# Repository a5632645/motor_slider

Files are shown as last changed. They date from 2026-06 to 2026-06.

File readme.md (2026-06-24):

# motor_slider
8个电动推子与MIDI CC的联动**原型机**测试

> [!NOTE]
> 本存储库含有大量AI生成内容，如果你不喜欢AI，请立刻返回

## 功能
8个电动推子，根据DAW MIDI CC移动位置，也能将电位器位置通过MIDI CC上传到DAW，两个操作不允许发生在同一时间，也不会进行抢占操作    
有7个推子含有原生PWM控制，另一个使用TIM+DMA写GPIO的形式模拟PWM  
电机控制器在小范围移动会产生可听的来回移动噪声  
MIDI CC目前固定为CC0~CC7  

## 额外内容
[购买电动线性电位器](https://item.taobao.com/item.htm?id=904405285742)

> 你说外壳，建议自己设计

> [!NOTE]
> 接下来的面板使用M3螺丝时选择平头的并且面板厚度不建议过厚，否则midi cc的范围会变成 2~124

立创面板源码，本人用的2.8mm(**别弄那么厚**)亚克力仍然会被压弯
```
{"type":"DOCHEAD"}||{"docType":"PANEL","client":"7755df130da93361","uuid":"ee90faf011b0bf49","updateTime":1781689268650,"version":"1781689268650"}|
{"type":"CANVAS","ticket":1,"id":"CANVAS"}||{"material":"acrylic","thickness":"2.0mm","print":"Ahead Side","craft":"Transparent","desc":"","coverColor":"white","width":"393mm","height":"579mm","originX":0,"originY":0,"orderWidth":"189.99mm","orderHeight":"151.89mm"}|
{"type":"POLY","ticket":2,"id":"e1584941ec573cd24"}||{"groupId":"0","layer":4,"rotation":0,"strokeWidth":0,"strokeStyle":"SOLID","strokeColor":"#000000","fillColor":"#000000","opacity":1,"autoClose":false,"ploys":[["ELLIPSE",0,0,1,1,0,0]],"displayFill":true,"displayStroke":true,"locked":false,"zIndex":10,"valid":true,"visible":true,"cover":1,"name":"","transScope":"PRINT&COVER","transPrint":0,"transWhite":0,"matrix":[6.889763779527534,0,380.7879488188978,0,6.889763779527534,1338.7758897637789]}|
{"type":"POLY","ticket":3,"id":"e18f4a7329a3ff436"}||{"groupId":"0","layer":4,"rotation":0,"strokeWidth":0,"strokeStyle":"SOLID","strokeColor":"#000000","fillColor":"#000000","opacity":1,"autoClose":false,"ploys":[["ELLIPSE",0,0,1,1,0,0]],"displayFill":true,"displayStroke":true,"locked":false,"zIndex":18,"valid":true,"visible":true,"cover":1,"name":"","transScope":"PRINT&COVER","transPrint":0,"transWhite":0,"matrix":[6.889763779527534,0,380.7849173228349,0,6.889763779527534,1811.2187007874004]}|
{"type":"POLY","ticket":4,"id":"ef68620ce32394071"}||{"groupId":"0","layer":4,"rotation":0,"strokeWidth":0,"strokeStyle":"SOLID","strokeColor":"#000000","fillColor":"#000000","opacity":1,"autoClose":false,"ploys":[["ELLIPSE",0,0,1,1,0,0]],"displayFill":true,"displayStroke":true,"locked":false,"zIndex":11,"valid":true,"visible":true,"cover":1,"name":"","transScope":"PRINT&COVER","transPrint":0,"transWhite":0,"matrix":[6.889763779527534,0,468.1925748031497,0,6.889763779527534,1338.779188976377]}|
{"type":"POLY","ticket":5,"id":"ee57a8df2610ad1db"}||{"groupId":"0","layer":4,"rotation":0,"strokeWidth":0,"strokeStyle":"SOLID","strokeColor":"#000000","fillColor":"#000000","opacity":1,"autoClose":false,"ploys":[["ELLIPSE",0,0,1,1,0,0]],"displayFill":true,"displayStroke":true,"locked":false,"zIndex":19,"valid":true,"visible":true,"cover":1,"name":"","transScope":"PRINT&COVER","transPrint":0,"transWhite":0,"matrix":[6.889763779527534,0,468.18954330708664,0,6.889763779527534,1811.2219999999984]}|
{"type":"POLY","ticket":6,"id":"e849a7849dee4361d"}||{"groupId":"0","layer":4,"rotation":0,"strokeWidth":0,"strokeStyle":"SOLID","strokeColor":"#000000","fillColor":"#000000","opacity":1,"autoClose":false,"ploys":[["ELLIPSE",0,0,1,1,0,0]],"displayFill":true,"displayStroke":true,"locked":false,"zIndex":12,"valid":true,"visible":true,"cover":1,"name":"","transScope":"PRINT&COVER","transPrint":0,"transWhite":0,"matrix":[6.889763779527534,0,555.5935748031496,0,6.889763779527534,1338.779188976377]}|
{"type":"POLY","ticket":7,"id":"e64859d853dfd7e9b"}||{"groupId":"0","layer":4,"rotation":0,"strokeWidth":0,"strokeStyle":"SOLID","strokeColor":"#000000","fillColor":"#000000","opacity":1,"autoClose":false,"ploys":[["ELLIPSE",0,0,1,1,0,0]],"displayFill":true,"displayStroke":true,"locked":false,"zIndex":20,"valid":true,"visible":true,"cover":1,"name":"","transScope":"PRINT&COVER","transPrint":0,"transWhite":0,"matrix":[6.889763779527534,0,555.5905433070866,0,6.889763779527534,1811.2219999999984]}|
{"type":"POLY","ticket":8,"id":"ecec94a499a380fba"}||{"groupId":"0","layer":4,"rotation":0,"strokeWidth":0,"strokeStyle":"SOLID","strokeColor":"#000000","fillColor":"#000000","opacity":1,"autoClose":false,"ploys":[["ELLIPSE",0,0,1,1,0,0]],"displayFill":true,"displayStroke":true,"locked":false,"zIndex":13,"valid":true,"visible":true,"cover":1,"name":"","transScope":"PRINT&COVER","transPrint":0,"transWhite":0,"matrix":[6.889763779527534,0,642.9955748031495,0,6.889763779527534,1338.779188976377]}|
{"type":"POLY","ticket":9,"id":"ef3ef9754e380944a"}||{"groupId":"0","layer":4,"rotation":0,"strokeWidth":0,"strokeStyle":"SOLID","strokeColor":"#000000","fillColor":"#000000","opacity":1,"autoClose":false,"ploys":[["ELLIPSE",0,0,1,1,0,0]],"displayFill":true,"displayStroke":true,"locked":false,"zIndex":21,"valid":true,"visible":true,"cover":1,"name":"","transScope":"PRINT&COVER","transPrint":0,"transWhite":0,"matrix":[6.889763779527534,0,642.9925433070866,0,6.889763779527534,1811.2219999999984]}|
{"type":"POLY","ticket":10,"id":"e9294cab0f8b4fe10"}||{"groupId":"0","layer":4,"rotation":0,"strokeWidth":0,"strokeStyle":"SOLID","strokeColor":"#000000","fillColor":"#000000","opacity":1,"autoClose":false,"ploys":[["ELLIPSE",0,0,1,1,0,0]],"displayFill":true,"displayStroke":true,"locked":false,"zIndex":14,"valid":true,"visible":true,"cover":1,"name":"","transScope":"PRINT&COVER","transPrint":0,"transWhite":0,"matrix":[6.889763779527534,0,730.3965748031495,0,6.889763779527534,1338.779188976377]}|
{"type":"POLY","ticket":11,"id":"ebccfad423ecd8b29"}||{"groupId":"0","layer":4,"rotation":0,"strokeWidth":0,"strokeStyle":"SOLID","strokeColor":"#000000","fillColor":"#000000","opacity":1,"autoClose":false,"ploys":[["ELLIPSE",0,0,1,1,0,0]],"displayFill":true,"displayStroke":true,"locked":false,"zIndex":22,"valid":true,"visible":true,"cover":1,"name":"","transScope":"PRINT&COVER","transPrint":0,"transWhite":0,"matrix":[6.889763779527534,0,730.3935433070866,0,6.889763779527534,1811.2219999999984]}|
{"type":"POLY","ticket":12,"id":"e99282393f4ec6fab"}||{"groupId":"0","layer":4,"rotation":0,"strokeWidth":0,"strokeStyle":"SOLID","strokeColor":"#000000","fillColor":"#000000","opacity":1,"autoClose":false,"ploys":[["ELLIPSE",0,0,1,1,0,0]],"displayFill":true,"displayStroke":true,"locked":false,"zIndex":15,"valid":true,"visible":true,"cover":1,"name":"","transScope":"PRINT&COVER","transPrint":0,"transWhite":0,"matrix":[6.889763779527534,0,817.7985748031496,0,6.889763779527534,1338.779188976377]}|
{"type":"POLY","ticket":13,"id":"e8b75c9436c282883"}||{"groupId":"0","layer":4,"rotation":0,"strokeWidth":0,"strokeStyle":"SOLID","strokeColor":"#000000","fillColor":"#000000","opacity":1,"autoClose":false,"ploys":[["ELLIPSE",0,0,1,1,0,0]],"displayFill":true,"displayStroke":true,"locked":false,"zIndex":23,"valid":true,"visible":true,"cover":1,"name":"","transScope":"PRINT&COVER","transPrint":0,"transWhite":0,"matrix":[6.889763779527534,0,817.7955433070866,0,6.889763779527534,1811.2219999999984]}|
{"type":"POLY","ticket":14,"id":"e2a41bdb96d65d63a"}||{"groupId":"0","layer":4,"rotation":0,"strokeWidth":0,"strokeStyle":"SOLID","strokeColor":"#000000","fillColor":"#000000","opacity":1,"autoClose":false,"ploys":[["ELLIPSE",0,0,1,1,0,0]],"displayFill":true,"displayStroke":true,"locked":false,"zIndex":16,"valid":true,"visible":true,"cover":1,"name":"","transScope":"PRINT&COVER","transPrint":0,"transWhite":0,"matrix":[6.889763779527534,0,905.2005748031496,0,6.889763779527534,1338.779188976377]}|
{"type":"POLY","ticket":15,"id":"e33940a38a94704ff"}||{"groupId":"0","layer":4,"rotation":0,"strokeWidth":0,"strokeStyle":"SOLID","strokeColor":"#000000","fillColor":"#000000","opacity":1,"autoClose":false,"ploys":[["ELLIPSE",0,0,1,1,0,0]],"displayFill":true,"displayStroke":true,"locked":false,"zIndex":24,"valid":true,"visible":true,"cover":1,"name":"","transScope":"PRINT&COVER","transPrint":0,"transWhite":0,"matrix":[6.889763779527534,0,905.1975433070867,0,6.889763779527534,1811.2219999999984]}|
{"type":"POLY","ticket":16,"id":"ee1f460c7b3ff9eb3"}||{"groupId":"0","layer":4,"rotation":0,"strokeWidth":0,"strokeStyle":"SOLID","strokeColor":"#000000","fillColor":"#000000","opacity":1,"autoClose":false,"ploys":[["ELLIPSE",0,0,1,1,0,0]],"displayFill":true,"displayStroke":true,"locked":false,"zIndex":17,"valid":true,"visible":true,"cover":1,"name":"","transScope":"PRINT&COVER","transPrint":0,"transWhite":0,"matrix":[6.889763779527534,0,992.6015748031497,0,6.889763779527534,1338.779188976377]}|
{"type":"POLY","ticket":17,"id":"e3b649b0d4ee38bb5"}||{"groupId":"0","layer":4,"rotation":0,"strokeWidth":0,"strokeStyle":"SOLID","strokeColor":"#000000","fillColor":"#000000","opacity":1,"autoClose":false,"ploys":[["ELLIPSE",0,0,1,1,0,0]],"displayFill":true,"displayStroke":true,"locked":false,"zIndex":25,"valid":true,"visible":true,"cover":1,"name":"","transScope":"PRINT&COVER","transPrint":0,"transWhite":0,"matrix":[6.889763779527534,0,992.5985433070867,0,6.889763779527534,1811.2219999999984]}|
{"type":"POLY","ticket":18,"id":"ec19dd633df9f9027"}||{"groupId":"0","layer":4,"rotation":0,"strokeWidth":0,"strokeStyle":"SOLID","strokeColor":"#000000","fillColor":"#000000","opacity":1,"autoClose":false,"ploys":[["ELLIPSE",0,0,1,1,0,0]],"displayFill":true,"displayStroke":true,"locked":false,"zIndex":26,"valid":true,"visible":true,"cover":1,"name":"","transScope":"PRINT&COVER","transPrint":0,"transWhite":0,"matrix":[6.889763779527534,0,327.16507480314976,0,6.889763779527534,1850.7869291338563]}|
{"type":"POLY","ticket":19,"id":"e5c19595f2625c8ff"}||{"groupId":"0","layer":4,"rotation":0,"strokeWidth":0,"strokeStyle":"SOLID","strokeColor":"#000000","fillColor":"#000000","opacity":1,"autoClose":false,"ploys":[["ELLIPSE",0,0,1,1,0,0]],"displayFill":true,"displayStroke":true,"locked":false,"zIndex":27,"valid":true,"visible":true,"cover":1,"name":"","transScope":"PRINT&COVER","transPrint":0,"transWhite":0,"matrix":[6.889763779527534,0,327.1644094488191,0,6.889763779527534,1306.3316220472423]}|
{"type":"POLY","ticket":20,"id":"e6e8d903b9c234424"}||{"groupId":"0","layer":4,"rotation":0,"strokeWidth":0,"strokeStyle":"SOLID","strokeColor":"#000000","fillColor":"#000000","opacity":1,"autoClose":false,"ploys":[["ELLIPSE",0,0,1,1,0,0]],"displayFill":true,"displayStroke":true,"locked":false,"zIndex":28,"valid":true,"visible":true,"cover":1,"name":"","transScope":"PRINT&COVER","transPrint":0,"transWhite":0,"matrix":[6.889763779527534,0,1040.9346889763783,0,6.889763779527534,1306.3313228346442]}|
{"type":"POLY","ticket":21,"id":"e58a1011d351861f7"}||{"groupId":"0","layer":4,"rotation":0,"strokeWidth":0,"strokeStyle":"SOLID","strokeColor":"#000000","fillColor":"#000000","opacity":1,"autoClose":false,"ploys":[["ELLIPSE",0,0,1,1,0,0]],"displayFill":true,"displayStroke":true,"locked":false,"zIndex":29,"valid":true,"visible":true,"cover":1,"name":"","transScope":"PRINT&COVER","transPrint":0,"transWhite":0,"matrix":[6.889763779527534,0,1040.9354921259842,0,6.889763779527534,1850.7872834645655]}|
{"type":"POLY","ticket":22,"id":"e03eb1e0feb6fb015"}||{"groupId":"0","layer":3,"rotation":0,"strokeWidth":0,"strokeStyle":"SOLID","strokeColor":"#000000","fillColor":"#000000","opacity":1,"autoClose":false,"ploys":[["R",0,0,1,1,0,0,0,0]],"displayFill":true,"displayStroke":true,"locked":false,"zIndex":9,"valid":true,"visible":true,"cover":1,"name":"","transScope":"PRINT&COVER","transPrint":0,"transWhite":0,"matrix":[748,-2.343515398637612e-15,311.00000000000006,-3.210431588880691e-15,597.9999999999999,1874]}|
{"type":"POLY","ticket":23,"id":"e8425d0d29416879a"}||{"groupId":"0","layer":1,"rotation":0,"strokeWidth":3.937007874015748,"strokeStyle":"SOLID","strokeColor":"#000000","fillColor":"#000000","opacity":1,"autoClose":false,"ploys":[["R",0,0,1,1,0,0,0,0]],"displayFill":false,"displayStroke":true,"locked":false,"zIndex":1,"valid":true,"visible":true,"cover":1,"name":"","transScope":"PRINT&COVER","transPrint":0,"transWhite":0,"matrix":[67.71653543307086,0,346.92671259842524,0,576.771653543307,1863.3824173228334]}|
{"type":"POLY","ticket":24,"id":"ed294a9686753e663"}||{"groupId":"0","layer":4,"rotation":0,"strokeWidth":0,"strokeStyle":"SOLID","strokeColor":"#000000","fillColor":"#000000","opacity":1,"autoClose":false,"ploys":[["R",0,0,1,1,0,0,0,0]],"displayFill":true,"displayStroke":true,"locked":false,"zIndex":30,"valid":true,"visible":true,"cover":1,"name":"","transScope":"PRINT&COVER","transPrint":0,"transWhite":0,"matrix":[9.842519685039406,0,375.8628543307085,0,433.07086614173227,1791.5328503936992]}|
{"type":"POLY","ticket":25,"id":"ef3a6cacf585e59a6"}||{"groupId":"0","layer":1,"rotation":0,"strokeWidth":3.937007874015748,"strokeStyle":"SOLID","strokeColor":"#000000","fillColor":"#000000","opacity":1,"autoClose":false,"ploys":[["R",0,0,1,1,0,0,0,0]],"displayFill":false,"displayStroke":true,"locked":false,"zIndex":2,"valid":true,"visible":true,"cover":1,"name":"","transScope":"PRINT&COVER","transPrint":0,"transWhite":0,"matrix":[67.71653543307086,0,434.3313385826771,0,576.771653543307,1863.3857165354316]}|
{"type":"POLY","ticket":26,"id":"e583333e3c7230aa1"}||{"groupId":"0","layer":4,"rotation":0,"strokeWidth":0,"strokeStyle":"SOLID","strokeColor":"#000000","fillColor":"#000000","opacity":1,"autoClose":false,"ploys":[["R",0,0,1,1,0,0,0,0]],"displayFill":true,"displayStroke":true,"locked":false,"zIndex":31,"valid":true,"visible":true,"cover":1,"name":"","transScope":"PRINT&COVER","transPrint":0,"transWhite":0,"matrix":[9.842519685039406,0,463.2674803149603,0,433.07086614173227,1791.5361496062974]}|
{"type":"POLY","ticket":27,"id":"eaf03c847e17b207d"}||{"groupId":"0","layer":1,"rotation":0,"strokeWidth":3.937007874015748,"strokeStyle":"SOLID","strokeColor":"#000000","fillColor":"#000000","opacity":1,"autoClose":false,"ploys":[["R",0,0,1,1,0,0,0,0]],"displayFill":false,"displayStroke":true,"locked":false,"zIndex":3,"valid":true,"visible":true,"cover":1,"name":"","transScope":"PRINT&COVER","transPrint":0,"transWhite":0,"matrix":[67.71653543307086,0,521.7323385826771,0,576.771653543307,1863.3857165354316]}|
{"type":"POLY","ticket":28,"id":"e2db45f8716f7ab01"}||{"groupId":"0","layer":4,"rotation":0,"strokeWidth":0,"strokeStyle":"SOLID","strokeColor":"#000000","fillColor":"#000000","opacity":1,"autoClose":false,"ploys":[["R",0,0,1,1,0,0,0,0]],"displayFill":true,"displayStroke":true,"locked":false,"zIndex":32,"valid":true,"visible":true,"cover":1,"name":"","transScope":"PRINT&COVER","transPrint":0,"transWhite":0,"matrix":[9.842519685039406,0,550.6684803149603,0,433.07086614173227,1791.5361496062974]}|
{"type":"POLY","ticket":29,"id":"eb4fa830be97bb013"}||{"groupId":"0","layer":1,"rotation":0,"strokeWidth":3.937007874015748,"strokeStyle":"SOLID","strokeColor":"#000000","fillColor":"#000000","opacity":1,"autoClose":false,"ploys":[["R",0,0,1,1,0,0,0,0]],"displayFill":false,"displayStroke":true,"locked":false,"zIndex":4,"valid":true,"visible":true,"cover":1,"name":"","transScope":"PRINT&COVER","transPrint":0,"transWhite":0,"matrix":[67.71653543307086,0,609.1343385826772,0,576.771653543307,1863.3857165354316]}|
{"type":"POLY","ticket":30,"id":"e0a4fecc1b48feb2d"}||{"groupId":"0","layer":4,"rotation":0,"strokeWidth":0,"strokeStyle":"SOLID","strokeColor":"#000000","fillColor":"#000000","opacity":1,"autoClose":false,"ploys":[["R",0,0,1,1,0,0,0,0]],"displayFill":true,"displayStroke":true,"locked":false,"zIndex":33,"valid":true,"visible":true,"cover":1,"name":"","transScope":"PRINT&COVER","transPrint":0,"transWhite":0,"matrix":[9.842519685039406,0,638.0704803149604,0,433.07086614173227,1791.5361496062974]}|
{"type":"POLY","ticket":31,"id":"ea5e9c516e7580935"}||{"groupId":"0","layer":1,"rotation":0,"strokeWidth":3.937007874015748,"strokeStyle":"SOLID","strokeColor":"#000000","fillColor":"#000000","opacity":1,"autoClose":false,"ploys":[["R",0,0,1,1,0,0,0,0]],"displayFill":false,"displayStroke":true,"locked":false,"zIndex":5,"valid":true,"visible":true,"cover":1,"name":"","transScope":"PRINT&COVER","transPrint":0,"transWhite":0,"matrix":[67.71653543307086,0,696.5353385826771,0,576.771653543307,1863.3857165354316]}|
{"type":"POLY","ticket":32,"id":"ed69e7dfbb81d9574"}||{"groupId":"0","layer":4,"rotation":0,"strokeWidth":0,"strokeStyle":"SOLID","strokeColor":"#000000","fillColor":"#000000","opacity":1,"autoClose":false,"ploys":[["R",0,0,1,1,0,0,0,0]],"displayFill":true,"displayStroke":true,"locked":false,"zIndex":34,"valid":true,"visible":true,"cover":1,"name":"","transScope":"PRINT&COVER","transPrint":0,"transWhite":0,"matrix":[9.842519685039406,0,725.4714803149603,0,433.07086614173227,1791.5361496062974]}|
{"type":"POLY","ticket":33,"id":"ee4c32a7e6f3f4fc2"}||{"groupId":"0","layer":1,"rotation":0,"strokeWidth":3.937007874015748,"strokeStyle":"SOLID","strokeColor":"#000000","fillColor":"#000000","opacity":1,"autoClose":false,"ploys":[["R",0,0,1,1,0,0,0,0]],"displayFill":false,"displayStroke":true,"locked":false,"zIndex":6,"valid":true,"visible":true,"cover":1,"name":"","transScope":"PRINT&COVER","transPrint":0,"transWhite":0,"matrix":[67.71653543307086,0,783.9373385826772,0,576.771653543307,1863.3857165354316]}|
{"type":"POLY","ticket":34,"id":"e7ed778951e0f1ca9"}||{"groupId":"0","layer":4,"rotation":0,"strokeWidth":0,"strokeStyle":"SOLID","strokeColor":"#000000","fillColor":"#000000","opacity":1,"autoClose":false,"ploys":[["R",0,0,1,1,0,0,0,0]],"displayFill":true,"displayStroke":true,"locked":false,"zIndex":35,"valid":true,"visible":true,"cover":1,"name":"","transScope":"PRINT&COVER","transPrint":0,"transWhite":0,"matrix":[9.842519685039406,0,812.8734803149604,0,433.07086614173227,1791.5361496062974]}|
{"type":"POLY","ticket":35,"id":"efc2624c844171aa8"}||{"groupId":"0","layer":1,"rotation":0,"strokeWidth":3.937007874015748,"strokeStyle":"SOLID","strokeColor":"#000000","fillColor":"#000000","opacity":1,"autoClose":false,"ploys":[["R",0,0,1,1,0,0,0,0]],"displayFill":false,"displayStroke":true,"locked":false,"zIndex":7,"valid":true,"visible":true,"cover":1,"name":"","transScope":"PRINT&COVER","transPrint":0,"transWhite":0,"matrix":[67.71653543307086,0,871.3393385826772,0,576.771653543307,1863.3857165354316]}|
{"type":"POLY","ticket":36,"id":"e7c086de920a9acdd"}||{"groupId":"0","layer":4,"rotation":0,"strokeWidth":0,"strokeStyle":"SOLID","strokeColor":"#000000","fillColor":"#000000","opacity":1,"autoClose":false,"ploys":[["R",0,0,1,1,0,0,0,0]],"displayFill":true,"displayStroke":true,"locked":false,"zIndex":36,"valid":true,"visible":true,"cover":1,"name":"","transScope":"PRINT&COVER","transPrint":0,"transWhite":0,"matrix":[9.842519685039406,0,900.2754803149604,0,433.07086614173227,1791.5361496062974]}|
{"type":"POLY","ticket":37,"id":"e8287a6ea15dcac1f"}||{"groupId":"0","layer":1,"rotation":0,"strokeWidth":3.937007874015748,"strokeStyle":"SOLID","strokeColor":"#000000","fillColor":"#000000","opacity":1,"autoClose":false,"ploys":[["R",0,0,1,1,0,0,0,0]],"displayFill":false,"displayStroke":true,"locked":false,"zIndex":8,"valid":true,"visible":true,"cover":1,"name":"","transScope":"PRINT&COVER","transPrint":0,"transWhite":0,"matrix":[67.71653543307086,0,958.7403385826772,0,576.771653543307,1863.3857165354316]}|
{"type":"POLY","ticket":38,"id":"e680f056dc145cdaa"}||{"groupId":"0","layer":4,"rotation":0,"strokeWidth":0,"strokeStyle":"SOLID","strokeColor":"#000000","fillColor":"#000000","opacity":1,"autoClose":false,"ploys":[["R",0,0,1,1,0,0,0,0]],"displayFill":true,"displayStroke":true,"locked":false,"zIndex":37,"valid":true,"visible":true,"cover":1,"name":"","transScope":"PRINT&COVER","transPrint":0,"transWhite":0,"matrix":[9.842519685039406,0,987.6764803149604,0,433.07086614173227,1791.5361496062974]}|
{"type":"AUXLINE","ticket":39,"id":"e78fae264d32af79d"}||{"groupId":"0","layer":8,"x":327.55781496063,"y":1850.786787401573,"rotation":0,"strokeWidth":0,"length":100,"locked":false,"visible":true,"cover":0,"name":"","zIndex":54}|
{"type":"AUXLINE","ticket":40,"id":"ee2bd2ee56e85e5eb"}||{"groupId":"0","layer":8,"x":327.1645944881891,"y":1883.0706535433055,"rotation":90,"strokeWidth":0,"length":100,"locked":false,"visible":true,"cover":0,"name":"","zIndex":55}|
{"type":"AUXLINE","ticket":41,"id":"e86db9603efb5b519"}||{"groupId":"0","layer":8,"x":1040.9349803149605,"y":1883.0705511811009,"rotation":90,"strokeWidth":0,"length":100,"locked":false,"visible":true,"cover":0,"name":"","zIndex":56}|
{"type":"AUXLINE","ticket":42,"id":"ebabefe86aa5f8d13"}||{"groupId":"0","layer":8,"x":326.77086614173254,"y":1306.3321181102347,"rotation":0,"strokeWidth":0,"length":100,"locked":false,"visible":true,"cover":0,"name":"","zIndex":57}|
{"type":"AUXLINE","ticket":43,"id":"ebd909c018683e468"}||{"groupId":"0","layer":8,"x":468.1895433070866,"y":1575.0000512529068,"rotation":0,"strokeWidth":0,"length":0,"locked":false,"visible":true,"cover":0,"name":"","zIndex":40}|
{"type":"AUXLINE","ticket":44,"id":"efa1f53fa5ae68d26"}||{"groupId":"0","layer":8,"x":555.5905433070866,"y":1575.0000512529068,"rotation":0,"strokeWidth":0,"length":0,"locked":false,"visible":true,"cover":0,"name":"","zIndex":41}|
{"type":"AUXLINE","ticket":45,"id":"ebb5dc5efb9204c62"}||{"groupId":"0","layer":8,"x":642.9925433070866,"y":1575.0000512529068,"rotation":0,"strokeWidth":0,"length":0,"locked":false,"visible":true,"cover":0,"name":"","zIndex":42}|
{"type":"AUXLINE","ticket":46,"id":"e73e467c0f45ccb31"}||{"groupId":"0","layer":8,"x":730.3935433070866,"y":1575.0000512529068,"rotation":0,"strokeWidth":0,"length":0,"locked":false,"visible":true,"cover":0,"name":"","zIndex":43}|
{"type":"AUXLINE","ticket":47,"id":"eac48020f18635c06"}||{"groupId":"0","layer":8,"x":817.7955433070866,"y":1575.0000512529068,"rotation":0,"strokeWidth":0,"length":0,"locked":false,"visible":true,"cover":0,"name":"","zIndex":44}|
{"type":"AUXLINE","ticket":48,"id":"eb4071d14bd4ca49d"}||{"groupId":"0","layer":8,"x":905.1975433070867,"y":1575.0000512529068,"rotation":0,"strokeWidth":0,"length":0,"locked":false,"visible":true,"cover":0,"name":"","zIndex":45}|
{"type":"AUXLINE","ticket":49,"id":"ed3d01fe15ed1ee86"}||{"groupId":"0","layer":8,"x":992.5985433070866,"y":1575.0000512529068,"rotation":0,"strokeWidth":0,"length":0,"locked":false,"visible":true,"cover":0,"name":"","zIndex":46}|
{"type":"DIMENSION","ticket":50,"id":"e41ac982d3f6c6d03"}||{"layer":8,"dimensionType":"LENGTH","unit":"","strokeWidth":0,"accuracy":0,"controlDot":[380.78491732283476,1811.2187007874004,429.5277283464569,1811.2187007874004,429.5277283464569,1338.775889763779,380.7879488188978,1338.775889763779],"relationIds":[],"locked":false,"zIndex":38,"visible":true,"cover":0,"name":"","valid":true,"rotation":0}|
{"type":"DIMENSION","ticket":51,"id":"e5a79f0815a55690b"}||{"layer":8,"dimensionType":"LENGTH","unit":"","strokeWidth":0,"accuracy":0,"controlDot":[380.7879488188978,1338.775889763779,357.92470540636003,1338.7757430585466,357.92318966431577,1574.9962154946286,380.78643307685354,1574.996362199861],"relationIds":[],"locked":false,"zIndex":39,"visible":true,"cover":0,"name":"","valid":true,"rotation":0}|
{"type":"DIMENSION","ticket":52,"id":"e1cdcaf0fb6a92284"}||{"layer":8,"dimensionType":"LENGTH","unit":"","strokeWidth":0,"accuracy":0,"controlDot":[414.64279921259845,1286.611188976375,414.64279921259845,1286.6104803149585,434.3277204724409,1286.6104803149585,434.3277204724409,1286.611787401572],"relationIds":[],"locked":false,"zIndex":47,"visible":true,"cover":0,"name":"","valid":true,"rotation":0}|
{"type":"DIMENSION","ticket":53,"id":"edc10f024f0ffa6eb"}||{"layer":8,"dimensionType":"LENGTH","unit":"","strokeWidth":0,"accuracy":0,"controlDot":[502.04742519685027,1286.6144881889732,502.04742519685027,1286.6137795275567,521.7323464566925,1286.6137795275567,521.7323464566925,1286.6150866141702],"relationIds":[],"locked":false,"zIndex":48,"visible":true,"cover":0,"name":"","valid":true,"rotation":0}|
{"type":"DIMENSION","ticket":54,"id":"eee07e3357b190a82"}||{"layer":8,"dimensionType":"LENGTH","unit":"","strokeWidth":0,"accuracy":0,"controlDot":[589.4484251968502,1286.6144881889732,589.4484251968502,1286.6137795275567,609.1333464566927,1286.6137795275567,609.1333464566927,1286.6150866141702],"relationIds":[],"locked":false,"zIndex":49,"visible":true,"cover":0,"name":"","valid":true,"rotation":0}|
{"type":"DIMENSION","ticket":55,"id":"e27bef0ec3e5497e1"}||{"layer":8,"dimensionType":"LENGTH","unit":"","strokeWidth":0,"accuracy":0,"controlDot":[676.8504251968502,1286.6144881889732,676.8504251968502,1286.6137795275567,696.5353464566928,1286.6137795275567,696.5353464566928,1286.6150866141702],"relationIds":[],"locked":false,"zIndex":50,"visible":true,"cover":0,"name":"","valid":true,"rotation":0}|
{"type":"DIMENSION","ticket":56,"id":"e288bcc642b5978d1"}||{"layer":8,"dimensionType":"LENGTH","unit":"","strokeWidth":0,"accuracy":0,"controlDot":[764.2514251968502,1286.6144881889732,764.2514251968502,1286.6137795275567,783.9363464566927,1286.6137795275567,783.9363464566927,1286.6150866141702],"relationIds":[],"locked":false,"zIndex":51,"visible":true,"cover":0,"name":"","valid":true,"rotation":0}|
{"type":"DIMENSION","ticket":57,"id":"ea360c81e44c1357d"}||{"layer":8,"dimensionType":"LENGTH","unit":"","strokeWidth":0,"accuracy":0,"controlDot":[851.6534251968502,1286.6144881889732,851.6534251968502,1286.6137795275567,871.3383464566928,1286.6137795275567,871.3383464566928,1286.6150866141702],"relationIds":[],"locked":false,"zIndex":52,"visible":true,"cover":0,"name":"","valid":true,"rotation":0}|
{"type":"DIMENSION","ticket":58,"id":"eaa61114e2d80f349"}||{"layer":8,"dimensionType":"LENGTH","unit":"","strokeWidth":0,"accuracy":0,"controlDot":[939.0554251968503,1286.6144881889732,939.0554251968503,1286.6137795275567,958.7403464566928,1286.6137795275567,958.7403464566928,1286.6150866141702],"relationIds":[],"locked":false,"zIndex":53,"visible":true,"cover":0,"name":"","valid":true,"rotation":0}
```

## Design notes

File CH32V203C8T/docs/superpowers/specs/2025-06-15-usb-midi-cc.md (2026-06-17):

# USB MIDI CC 双向联动 设计

> **日期:** 2025-06-15
> **关联:** `midi_cc.md`, `2025-06-12-closed-loop-control.md`, `2025-06-12-motor-control.md`

## 1. 概述

在现有 USB HID 功能不变的前提下，扩展为 USB 复合设备，新增 USB MIDI 1.0 类接口，实现八路马达线性电位器位置与 MIDI CC 消息的双向联动。

### 约束

- 不修改现有 HID 描述符、端点配置、轮询行为
- 不引入动态内存分配，所有缓冲区静态分配

---

## 2. USB 设备结构

### 2.1 复合设备拓扑

```
USB Device (bcdUSB=0x0200, Class=0xEF/0x02/0x01 Composite)
└── Configuration Descriptor (1 config)
    ├── Interface 0: HID0 (printf 调试输出, IN only) — 不变
    ├── Interface 1: HID1 (电机控制, IN + OUT) — 不变
    ├── Interface Association Descriptor (IAD)
    │   ├── bFunctionClass=1 (Audio)
    │   ├── bFunctionSubClass=3 (MIDIStreaming)
    │   └── bFunctionProtocol=0
    │   │
    │   ├── Interface 2: Audio Control (bClass=1, bSubClass=1)
    │   │   └── 无端点
    │   │
    │   └── Interface 3: MIDI Streaming (bClass=1, bSubClass=3)
    │       ├── Bulk IN  EP (0x84, 64 bytes) — MCU → Host
    │       └── Bulk OUT EP (0x05, 64 bytes) — Host → MCU
```

### 2.2 端点分配

| 端点 | 方向 | 用途 | 类型 | 包大小 |
|---|---|---|---|---|
| EP0 | 双向 | 控制传输 | Control | 64 |
| EP1 | IN (0x81) | HID0 printf | Interrupt | 64 |
| EP2 | IN (0x82) | HID1 状态上报 | Interrupt | 64 |
| EP3 | OUT (0x03) | HID1 命令接收 | Interrupt | 64 |
| **EP4** | **IN (0x84)** | **MIDI Bulk TX** | **Bulk** | **64** |
| **EP5** | **OUT (0x05)** | **MIDI Bulk RX** | **Bulk** | **64** |

### 2.3 描述符变更

**Device Descriptor (`usb_desc.cpp`)**
- `bcdUSB`: `0x0110` → `0x0200`
- `bDeviceClass`/`bDeviceSubClass`/`bDeviceProtocol`: 保持 `0xEF`/`0x02`/`0x01`（`.Composite()` 调用）

**Configuration Descriptor (`usb_desc.cpp`)**
- 在现有两个 HID Interface 之后追加 IAD + AC Interface + MIDI Streaming Interface
- 使用 tpusb 基础设施：`InterfaceAssociation`, `uac2::AudioFunction`, `midiv1::MIDIStreamInterface`, `midiv1::MidiEndpoint`

**字符串描述符**
- 保持不变

---

## 3. MIDI 数据格式

### 3.1 USB MIDI Event Packet (4 字节)

```
Byte 0: Cable Number (高4位) | Code Index Number (低4位)
Byte 1: MIDI Status Byte  (e.g. 0xB0 | channel)
Byte 2: MIDI Data Byte 1  (CC 编号)
Byte 3: MIDI Data Byte 2  (CC 值)
```

本设计仅处理 **Control Change (CC)** 消息，CIN = `0x0B`，Cable Number = `0x00`。

### 3.2 数值映射

```
电位器原始值 (0~4095) → MIDI CC (0~127)
  cc_value = raw_adc * 127 / 4095

MIDI CC (0~127) → 目标位置 (0~4095)
  target_pos = cc_value * 4095 / 127
```

---

## 4. TX 方向：电位器 → MIDI CC 发送

### 4.1 触发条件

- 在 1kHz 控制循环中，每路 ADC 更新后检查位置变化
- 仅当映射后的 CC 值与 `last_sent_cc[i]` **不同**时，才发送

### 4.2 阻塞接口模式

FIFO 满时**循环等待**而非丢弃（MIDI CC 消息不允许丢包），Flush 全部由 SysTick 驱动：

```c
// 检查连接 → 等待空间 → 入队（不触发 Flush）
void MidiCC_Send(uint8_t idx, uint8_t cc_value) {
    if (!HID_IsConnected())       // USB 未连接时跳过
        return;
    // 构造 4 字节 Event Packet
    uint8_t packet[4] = {
        0x0B,                     // CIN=0x0B (CC), Cable=0
        (uint8_t)(0xB0 | kMidiCcMap[idx].channel),
        kMidiCcMap[idx].cc_num,
        cc_value
    };
    // 等待 FIFO 有足够空间（循环等待，由 SysTick 消费腾空）
    while (Kfifo_FreeSpace(&midi_tx_fifo_.fifo) < 4) {
        // SysTick_Handler 中的 MidiCC_Flush() 会在此循环期间被响应
    }
    Kfifo_TryPush(&midi_tx_fifo_.fifo, packet, 4);
}
```

- `MidiCC_Send()` 为**阻塞式**：入队前循环等待 FIFO 空间，入队后立即返回
- **不调用** `MidiCC_Flush()` — 全部由 `SysTick_Handler` 周期性发送
- USB 未连接时 (`using_configuration == 0`)，静默丢弃，不浪费 CPU
- 等待发生在 **主循环上下文**（`Motor_RunControlLoop` 内），SysTick 中断仍正常响应并消费 FIFO

### 4.3 TX 数据流

```
Motor_RunControlLoop()  — 1kHz 控制上下文
  → 读取 ADC, 计算映射 cc_value
  → if !fader_rx_active[i] && cc_value != last_sent_cc[i]:
      → MidiCC_Send(i, cc_value)          // 仅入队，不 Flush
      → last_sent_cc[i] = cc_value

SysTick_Handler (1ms)    — 周期性发送
  → MidiCC_Flush()
    → if midi_tx_busy: return
    → 从 midi_tx_fifo_ 读取最多 64 字节 (16 packets)
    → 填充 midi_ep4_tx_buf_
    → midi_tx_busy = true
    → USBFSD->UEP4_TX_LEN = to_read
    → 触发 Bulk IN 传输

EP4 IN Complete 中断      — 流水线递送
  → midi_tx_busy = false
  → 递归 MidiCC_Flush() 直到 FIFO 空
```

### 4.4 Bulk 零包 (ZLP) 处理

Bulk 传输要求任何 **恰好 64 字节**（wMaxPacketSize 整数倍）的数据包后，需发送零长度包 (ZLP) 以标记传输结束，否则主机会等待更多数据。

```c
// Flush 内部逻辑：
uint32_t to_read = Kfifo_Size(&midi_tx_fifo_);
if (to_read == 0) {
    if (midi_zlp_needed_) {
        midi_zlp_needed_ = false;
        USBFSD->UEP4_TX_LEN = 0;          // 发送 ZLP
        midi_tx_busy = true;
    }
    return;
}
if (to_read > 64)
    to_read = 64;
// 从 FIFO 读取到 midi_ep4_tx_buf_
midi_zlp_needed_ = (to_read == 64);       // 若恰好 64 字节，标记需要 ZLP
USBFSD->UEP4_TX_LEN = to_read;
midi_tx_busy = true;
```

- `midi_zlp_needed_` 在发送 64 字节时置位
- 下次 `MidiCC_Flush()` 在 FIFO 空时检测到此标志，发送 ZLP
- ZLP 发送后清除标志，恢复正常 NAK 状态

### 4.5 Flush 调用链

```
SysTick_Handler (1ms)
  → Tick_Increment()
  → HID_Flush()              // HID0 printf 原样保留
  → MidiCC_Flush()           // MIDI TX flush（新增）

EP4 IN Complete 中断
  → midi_tx_busy = false
  → MidiCC_Flush()           // 递归发送下一批
```

- **SysTick** 提供周期性发送机会，确保 FIFO 中的数据不会长期滞留
- **EP4 IN Complete** 实现流水线：一批发送完成后立即发送下一批，最大化吞吐

### 4.6 缓冲区

```c
#define MIDI_TX_FIFO_SIZE 128   // 32 个 MIDI Event Packet
static struct {
    struct Kfifo fifo;
    uint8_t buf[MIDI_TX_FIFO_SIZE];
} midi_tx_fifo_;

__attribute__((aligned(4))) static uint8_t midi_ep4_tx_buf_[64];

static volatile bool midi_tx_busy_;
static bool midi_zlp_needed_;   // 非 volatile，仅主循环/SysTick 访问
```

---

## 5. RX 方向：MIDI CC → 电位器驱动

### 5.1 数据流

RX 采用**中断仅记录 + NAK，主线程消费**的简单设计：

```
EP5 OUT Complete (中断)
  → if midi_rx_pending_len_ > 0:
      return                                    // 上一包尚未消费，NAK 已设置
  → len = USBFSD->RX_LEN
  → if len == 0:
      USBFSD->UEP5_RX_CTRL = ACK                // ZLP 直接 ACK，无需处理
      return
  → midi_rx_pending_len_ = len                  // 记录数据长度
  → USBFSD->UEP5_RX_CTRL = NAK                  // NAK，数据留在 DMA 缓冲区等待主线程

App_Loop() 主循环
  → MidiCC_ProcessRx()
    → if midi_rx_pending_len_ == 0:
        return
    → 从 midi_ep5_rx_buf_ 中以 4 字节为单位解析 Event Packet
    → for offset = 0; offset + 3 < midi_rx_pending_len_; offset += 4:
      → 解析 CIN/Status/Data1/Data2
      → if (status & 0xF0) == 0xB0:   // CC 消息
          → 查 CC 映射表 → 定位电位器编号
          → 反向映射: target_pos = cc_value * 4095 / 127
          → fader_rx_active[idx] = true
          → Motor_SetTarget(idx, target_pos)
      → 非 CC 消息静默丢弃
    → midi_rx_pending_len_ = 0
    → USBFSD->UEP5_RX_CTRL = ACK                // 全部消耗，重新武装 EP5
```

**原理说明：**

- 中断中**不操作 FIFO**，仅记录长度 + NAK，最小化中断耗时
- 主机收到 NAK 后自动重试同一 OUT 事务，硬件将相同数据重新写入 DMA 缓冲区，数据安全
- ZLP（零长度包）无需处理，直接 ACK
- 主循环直接解析 USB DMA 缓冲区，全部消耗完后 ACK
- NAK 期间后续 OUT 中断因 `midi_rx_pending_len_ > 0` 而直接返回

### 5.2 缓冲区

```c
__attribute__((aligned(4))) static uint8_t midi_ep5_rx_buf_[64];
static volatile uint8_t midi_rx_pending_len_;    // 0 = 无待处理数据
```

---

## 6. 防回环

### 6.1 原理

当 MCU 正在响应 RX 命令驱动某路电位器时，该路电位器的位置变化不得触发 TX 发送。

### 6.2 实现

```c
static bool fader_rx_active_[kMotorIdx_Count];

// RX 驱动时置位
void MidiCC_SetRxActive(uint8_t idx, bool active) {
    if (idx < kMotorIdx_Count)
        fader_rx_active_[idx] = active;
}

// TX 检测时跳过被标记通道
// (在 MidiCC_CheckAndSend 中实现)

// 清除时机：
// 1. Motor_RunControlLoop 中 active_ 从 true → false 时清除
// 2. 超时 1000ms (CTRL_TIMEOUT_MS) 强制清除
```

### 6.3 清除逻辑

在 `Motor_RunControlLoop()` 中，每路电机到达目标或超时停止后（`active_` 从 `true` → `false`），调用 `MidiCC_SetRxActive(i, false)`。

若电机在 `CTRL_TIMEOUT_MS` (1000ms) 内未到达目标，控制超时机制会停止电机并清除 `active_`，防回环标志随之清除。

---

## 7. CC 映射配置

### 7.1 默认映射表

| 电位器编号 | MIDI 通道 (1-based) | CC 编号 |
|:---:|:---:|:---:|
| 0 | 1 | 0 |
| 1 | 1 | 1 |
| 2 | 1 | 2 |
| 3 | 1 | 3 |
| 4 | 1 | 4 |
| 5 | 1 | 5 |
| 6 | 1 | 6 |
| 7 | 1 | 7 |

### 7.2 代码定义

```c
struct MidiCcMapping {
    uint8_t channel;  // 0-based (0=Channel 1)
    uint8_t cc_num;   // CC 编号 (0~127)
};

static const struct MidiCcMapping kMidiCcMap[kMotorIdx_Count] = {
    {0, 0},   // 电位器0 → Channel 1, CC 0
    {0, 1},   // 电位器1 → Channel 1, CC 1
    {0, 2},   // 电位器2 → Channel 1, CC 2
    {0, 3},   // 电位器3 → Channel 1, CC 3
    {0, 4},   // 电位器4 → Channel 1, CC 4
    {0, 5},   // 电位器5 → Channel 1, CC 5
    {0, 6},   // 电位器6 → Channel 1, CC 6
    {0, 7},   // 电位器7 → Channel 1, CC 7
};
```

---

## 8. 文件变更清单

### 8.1 新增文件

| 文件 | 内容 |
|---|---|
| `User/usb/midi_cc.h` | MIDI CC 模块公共 API 声明 + 常量 + 映射表 |
| `User/usb/midi_cc.c` | MIDI CC 模块实现：TX/RX FIFO 管理、包解析、发送逻辑 |

### 8.2 修改文件

| 文件 | 改动 |
|---|---|
| `User/usb/usb_desc.cpp` | bcdUSB 0x0110→0x0200；追加 IAD + AC + MIDI Streaming 描述符 |
| `User/usb/usb_impl.h` | 新增 MIDI 端点地址常量 (`kMidiEpAddr_In=0x84`, `kMidiEpAddr_Out=0x05`) |
| `User/usb/usb_impl.c` | `UsbImpl_InitAndOpenEndpoints()` 配置 EP4/EP5；`UsbImpl_EpInComplete` 处理 EP4；`UsbImpl_EpOutComplete` 处理 EP5 |
| `User/bsp/ch32v20x_it.c` | `SysTick_Handler()` 追加 `MidiCC_Flush()` 调用 |
| `User/app/app.c` | `App_Init()` 调用 `MidiCC_Init()`；主循环中调用 `MidiCC_ProcessRx()` |
| `User/app/motor.c` | `Motor_RunControlLoop()` 中 ADC 更新后调用 `MidiCC_CheckAndSend()`；电机停止时清除防回环标志 |
| `User/config.h` | 可选：新增 `MIDI_TX_FIFO_SIZE` / `MIDI_RX_FIFO_SIZE` 配置宏 |

### 8.3 不变文件

| 文件 | 说明 |
|---|---|
| `User/usb/usb_device.c/h` | USB 设备核心状态机，无改动 |
| `User/usb/usb_endpoint.h` | 端点类型枚举，无改动 |
| `User/usb/usb_hardware.h` | USB 寄存器别名，无改动 |
| `User/bsp/motor_hw.c/h` | 硬件 PWM/ADC 层，无改动 |
| `User/app/pid.c/h` | PID 控制器，无改动 |

---

## 9. 非功能需求

| 编号 | 描述 | 实现保证 |
|---|---|---|
| NF1 | 电位器变化到 MIDI CC 发出，端到端延迟 < 10 ms | 1kHz 控制循环中入队，SysTick 1ms 周期发送，最大延迟 < 2ms |
| NF2 | MIDI 接口不影响 HID 接口的轮询周期与响应时间 | MIDI Bulk 传输使用独立端点，中断分离处理 |
| NF3 | Windows 下无需额外驱动 | Class-compliant USB MIDI 1.0，AC + MS 接口标准描述符 |
| NF4 | 不引入动态内存分配 | 所有缓冲区 `static` 静态分配 |

---

## 10. 验收标准

1. **枚举验证**：设备插入后设备管理器同时出现 HID 设备与 "USB 音频设备" 条目
2. **TX 验证**：推动电位器，MIDI-OX 收到对应 CC 消息，值随位置线性变化
3. **RX 验证**：通过 MIDI 工具发送 CC，对应电位器自动移动到目标位置
4. **防回环验证**：RX 驱动期间，MIDI 监视器不出现该路 TX CC 消息
5. **HID 兼容性验证**：MIDI 功能开启后，原有 HID 读写功能行为不变

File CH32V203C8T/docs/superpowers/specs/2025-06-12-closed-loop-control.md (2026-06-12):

# 闭环控制 + HID1 命令协议 设计

> **日期:** 2025-06-12
> **关联:** `2025-06-12-control-state-machine.md`, `2025-06-12-potentiometer-ui-rework.md`

## HID1 通信协议

### 64 字节状态报告 (IN, MCU → Host)

| 偏移 | 大小 | 字段 | 说明 |
|---|---|---|---|
| 0 | 1 | `flags` | bit0=running, bit1=any_active |
| 1 | 1 | `active_flags` | 每路 1 bit, bit0=CH1 active, ... bit7=CH8 active |
| 2~17 | 16 | `adc[8]` | 8 × uint16 LE, 当前 ADC 值 (0~4095) |
| 18~33 | 16 | `target[8]` | 8 × uint16 LE, 目标 ADC 值 (0~4095) |
| 34~49 | 16 | `duty[8]` | 8 × uint16 LE, 当前占空比 (0~999) |
| 50~63 | 14 | 保留 | 填 0 |

### 64 字节命令报告 (OUT, Host → MCU)

| 偏移 | 大小 | 字段 | 说明 |
|---|---|---|---|
| 0 | 1 | `cmd` | 命令 ID |
| 1~16 | 16 | `payload` | 命令参数 |
| 17~63 | 47 | 保留 | 填 0 |

**命令定义:**

| cmd | 名称 | payload 格式 | 行为 |
|-----|---|---|---|
| `0x01` | 设置目标 | bytes 1-16: 8 × uint16 LE 目标值 | 调用 `Motor_SetTarget(i, val)` 激活各电机 |
| `0x02` | 读取状态 | 无 | 强制刷新 IN 报告（已由 1kHz 状态机自动完成） |
| `0x03` | 停止所有 | 无 | 调用 `Motor_StopAll()` 停所有电机 |

---

## 电机停止条件

每路电机独立状态机，在 `Motor_RunControlLoop` 中执行：

```
active_=false ───→ 收到新目标 ───→ active_=true, timeout_=1000
                    ┌──────────────┴──────────────┐
                    │ 每 1ms 迭代:                  │
                    │  if |target-adc| ≤ 2          │
                    │    → active_=false, PWM=0     │
                    │  else if --timeout_ == 0      │
                    │    → active_=false, PWM=0     │
                    │  else                         │
                    │    → PID → PWM                │
                    └──────────────────────────────┘
```

停止后电机输出为 0（coast 模式），用户可以自由拨动电位器。

---

## 固件改动

| 文件 | 改动 |
|---|---|
| `motor.h` | `struct MotorState` 新增 `bool active_`, `uint16_t timeout_` |
| | `Motor_GetStatus()` 新增 `uint8_t* active_flags` 参数 |
| | `Motor_InitControl()` 初始化 `active_=false, timeout_=0` |
| `motor.c` | `Motor_RunControlLoop()` 加入 active/timeout 判断 |
| | `Motor_SetTarget()` 激活电机 + 重置 timeout + 重置 PID 积分 |
| | `Motor_StopAll()` 设所有 `active_=false` |
| | `Motor_GetStatus()` 填充 `active_flags` |
| `usb_impl.h` | `HID1_ACTIVE_FLAGS = 1` 取代 `HID1_RSV` |
| | `HID1_SendStatus()` 新增 `uint8_t active_flags` 参数 |
| `usb_impl.c` | `HID1_SendStatus()` 填充 `active_flags` 字节 |
| | `HID1_ProcessCommand()` 实现 `0x01` 和 `0x03` 命令 |
| `main.c` | CONTROL 状态调用 `Motor_GetStatus` + `HID1_SendStatus` 同步新增参数 |

## 上位机改动

| 改动 | 说明 |
|---|---|
| `HidWorker` 增加 `send_target(ch, value)` 方法 | 组装 OUT 报告 → `device.write()` |
| `PotWidget._on_slider_changed` | 拖动滑块后调用 `HidWorker.send_target()` |
| `StatusReport` 解析 `active_flags` | 可选显示 |

### OUT 报告发送实现

```python
def send_targets(self, targets: List[int]):
    """通过 HID1 OUT 发送 8 路目标值"""
    report = bytearray(64)
    report[0] = 0x01  # cmd: 设置目标
    for i in range(8):
        report[1 + i*2] = targets[i] & 0xFF
        report[1 + i*2 + 1] = (targets[i] >> 8) & 0xFF
    try:
        self._device.write(bytes(report))
    except Exception:
        pass  # 连接断开时静默忽略
```

---

## 可配置参数 (`User/config.h`)

| 宏 | 默认值 | 说明 |
|----|---|---|
| `CTRL_ERROR_THRESHOLD` | 2 | ADC 误差阈值，在此范围内视为到达目标 |
| `CTRL_TIMEOUT_MS` | 1000 | 闭环超时 (ms)，超时未到达则停电机 |
| `PID_DEFAULT_KP` | 0.5 | 默认比例增益 |
| `PID_DEFAULT_KI` | 0.01 | 默认积分增益 |
| `PID_DEFAULT_KD` | 0.1 | 默认微分增益 |
| `PID_OUTPUT_MIN` | -999.0 | PID 输出下限（对应 PWM=0） |
| `PID_OUTPUT_MAX` | 999.0 | PID 输出上限（对应 PWM=999） |
| `PID_INTEGRAL_LIMIT` | 500.0 | 积分限幅，防止积分饱和 |
| `PWM_MIN_START_DUTY` | 100 | 电机起步最小占空比，克服静摩擦 (0~999) |
| `MOTOR3_DEADBAND` | 20 | 电机 3 开关死区（GPIO 控制） |
| `HID_FIFO_SIZE` | 512 | HID0 printf FIFO 大小 (字节) |

---

## 附：现有代码接入 config.h

将当前固件中散落的硬编码数值替换为 `config.h` 宏引用。

| 文件 | 行/位置 | 硬编码值 | 替换为 |
|---|---|---|---|
| `motor.c` | `Motor_InitControl` | `Pid_Init(..., 0.5f, 0.01f, 0.1f)` | `PID_DEFAULT_KP`, `KI`, `KD` |
| `pid.c` | `Pid_Init` | `output_min_ = -999.0f` | `PID_OUTPUT_MIN` |
| | | `output_max_ = 999.0f` | `PID_OUTPUT_MAX` |
| | | `integral_limit_ = 500.0f` | `PID_INTEGRAL_LIMIT` |
| `motor.c` | `Motor_RunControlLoop` 电机 3 | `if (diff > 20)` | `MOTOR3_DEADBAND` |
| `usb_impl.c` | 文件顶部 | `#define HID_FIFO_SIZE 512` | 改为 `#include "config.h"` 移除重复定义 |

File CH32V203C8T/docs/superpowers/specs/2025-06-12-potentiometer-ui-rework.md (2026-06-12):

# 电位器 UI 重构设计

> **日期:** 2025-06-12
> **关联文件:** `hid_adc_monitor.py`

## 目标

将当前列表式 ADC 显示（`QTableWidget`）替换为 8 个水平排列的电位器部件，每个部件包含可拖动的 Slider、ADC 指示器和 PWM 数字显示。保留底部调试控制台。

## 布局

```
┌──────────────────────────────────────────────────────────────┐
│  HID ADC Monitor       ● HID1 ● HID0               33 fps  │
├──────────────────────────────────────────────────────────────┤
│                                                              │
│  CH1     CH2     CH3     CH4     CH5     CH6     CH7     CH8 │
│ ┌────┐ ┌────┐ ┌────┐ ┌────┐ ┌────┐ ┌────┐ ┌────┐ ┌────┐  │
│ │║   │ │ ║  │ │  ║ │ │   ║│ │║   │ │ ║  │ │  ║ │ │   ║│  │
│ │║───│ │ ║──│ │──║ │ │───║│ │║───│ │ ║──│ │──║ │ │───║│  │
│ │║   │ │ ║  │ │  ║ │ │   ║│ │║   │ │ ║  │ │  ║ │ │   ║│  │
│ └────┘ └────┘ └────┘ └────┘ └────┘ └────┘ └────┘ └────┘  │
│PWM:123 PWM: 50 PWM:500 PWM:  0 PWM:200 PWM:350 PWM: 80 PWM:0│
│                                                              │
├──────────────────────────────────────────────────────────────┤
│ [HID0: ●]                                         [Clear]   │
│ SystemClk:96000000                                            │
│ USB HID ready                                                 │
└──────────────────────────────────────────────────────────────┘
```

## 每个电位器部件

### 组成

| 元素 | 类型 | 说明 |
|---|---|---|
| **Slider** | 可拖动 `QSlider`，垂直，0~4095 | 设置目标位置，滑块位置对应 `target_adc` |
| **ADC 指示器** | 自定义 `QPainter` 绘制：竖线 + 横线 | 仅显示当前 `current_adc`，不可交互 |
| **PWM 数字** | `QLabel` | 显示 `duty` 原始值 |
| **CH 标签** | `QLabel` | 显示 "CH1" ~ "CH8" |

### Slider 交互

- 拖动 Slider 时更新本地目标值显示
- 本次**不发送 HID1 OUT 命令**到固件（后续扩展）
- 范围 0~4095，对齐 ADC 分辨率

### ADC 指示器绘制

每个指示器是一根垂直线（表示 0~4095 范围），在对应 ADC 值的垂直位置画一条水平短线作为标记。

## 自适应

- 8 个部件放在 `QHBoxLayout` 中，每个宽度 = `可用宽度 / 8`
- 高度由 `QSplitter` 上半部分决定
- 窗口缩小时 8 列同步缩小

## 代码变更

### 移除

- `QTableWidget` 及其相关代码（`_table`, `COL_*` 常量, `ProgressBarDelegate`, `_bar_delegate` 等）
- `QHeaderView` 导入
- `QStyledItemDelegate` 导入

### 新增

- `class PotWidget(QWidget)` — 自定义电位器控件，含 `QSlider` + ADC 指示器绘制 + `QLabel`
- 8 个 `PotWidget` 实例水平排列
- `_update_pots(StatusReport)` 替换 `_on_data` 中的表格更新逻辑

### 保留

- `HidWorker` / `HidDebugWorker` / `StatusReport`
- 调试控制台（`QPlainTextEdit`）
- 状态栏 / FPS / 连接指示

## 文件

仅修改 `hid_adc_monitor.py` 一个文件。

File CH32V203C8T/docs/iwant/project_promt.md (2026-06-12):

## 概括
此项目是一个八路电动线性电位器的测试板，驱动器是DRV8833，由4个定时器的14路PWM驱动，其中仅有TIM4的PWM1和PWM2通道未被使用，因为被USB引脚占用了，因此是使用GPIO控制。

## 硬件连接
| 电机序号 | ADC通道 | ADC引脚 | 定时器以及通道(格式:A/B) | 定时器引脚(格式:A/B) |
| --- | --- | --- | --- | -- |
| 1 | 0 | PA0 | TIM3.3/TIM3.4 | PB0/PB1 |
| 2 | 1 | PA1 | TIM2.4/TIM2.3 | PB11/PB10 |
| 3 | 2 | PA2 | None/None | PB14/PB15 |
| 4 | 3 | PA3 | TIM1.2/TIM1.1 | PA9/PA8 |
| 5 | 4 | PA4 | TIM1.3/TIM1.4 | PA10/PA11 |
| 6 | 5 | PA5 | TIM2.2/TIM2.1 | PB3/PA15 |
| 7 | 6 | PA6 | TIM3.1/TIM3.2 | PB4/PB5 |
| 8 | 7 | PA7 | TIM4.4/TIM4.3 | PB9/PB8 |

### 驱动器与电机控制
- **驱动器**: DRV8833 × 2 或等效，每路 IN1/IN2 各一路独立 PWM
- **控制方式**: IN1=PWM，IN2=PWM（两路独立 PWM 实现正反转 + 衰减模式）
- **电机 3**: 无硬件定时器 PWM，使用 PB14(IN1)/PB15(IN2) 做 GPIO 开关控制（仅启停）
- **nSLEEP**: 固定高电平，常开

## 数据手册
已知TIM1为高级定时器，其他为通用定时器。
TIM1在 PB2总线上， 其他在 PB1总线上。

## 时钟配置
当前系统时钟：SYSCLK = **96MHz**（HSE=8MHz → PLL×12）。

| 总线 | 分频 | 时钟 | 挂载的定时器 |
|---|---|---|---|
| AHB (HCLK) | ÷1 | 96 MHz | SysTick |
| APB2 (PCLK2) | ÷1 | 96 MHz | TIM1（高级定时器） |
| APB1 (PCLK1) | ÷2 | 48 MHz | TIM2、TIM3、TIM4（通用定时器） |

APB1 预分频器为 ÷2，定时器时钟自动倍乘 ×2，因此所有定时器时钟均为 **96 MHz**。

## 控制要求
- PWM 频率 ≥ **30 kHz**
- PWM 分辨率：**1000 级**（ARR = 999），边沿对齐（向上计数）
- 实际 PWM 频率 = 96 MHz / 1000 = **96 kHz**（满足要求）
- 控制模式：**闭环位置控制**（ADC 位置反馈 → PID → PWM 输出）
- 控制周期：**1 kHz**（每 1ms 完成一轮 8 路 ADC→PID→PWM）
- 8 路电机可**同时独立运动**
- 堵转检测：ADC 位置长时间不变 + 正在驱动 = 堵转，无需硬件限位开关

## USB 与通信
- 通信接口：**自定义 HID 报告**（64 字节，通过 USB FS）
- 两个独立的 HID 接口：
  - **HID0** — printf 调试输出（仅 IN，现有实现）
  - **HID1** — 电机控制（IN + OUT，接收命令/发送状态）
- 上位机通过 HID OUT 报告发送目标位置等命令

## 固件架构：定时器驱动流水线

```
SysTick (1kHz 中断)
  └→ 软件触发 ADC (常规组, 8通道扫描, DMA)
      └→ DMA 完成中断
          └→ 从 DMA 缓冲区读取 8 路转换结果
              └→ 8 路 PID 计算
                  └→ 更新 PWM 比较值 / GPIO 输出
```

### 说明
- **TIM1~TIM4** 全部用于 PWM 输出，无法用作触发源，因此 **SysTick** 承担 1kHz 控制节拍
- **ADC**: 12 位分辨率，常规组 scan 模式，DMA 自动搬运 8 通道结果到内存缓冲区，软件触发
- **PA11/PA12**: 已分配给 USBFS 外设（USBD），TIM1_CH4 等与此无冲突
- **PID**: 在 DMA 完成中断中顺序计算 8 路，直接写 PWM 比较寄存器
- **HID**: 在主循环中处理 IN/OUT 报告的收发，不干扰控制时序

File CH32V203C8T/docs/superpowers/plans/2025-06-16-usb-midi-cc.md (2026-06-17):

# USB MIDI CC 双向联动 实现计划

> **For agentic workers:** REQUIRED SUB-SKILL: Use superpowers:subagent-driven-development (recommended) or superpowers:executing-plans to implement this plan task-by-task. Steps use checkbox (`- [ ]`) syntax for tracking.

**Goal:** 在现有 USB HID 功能不变的前提下，为八路马达线性电位器固件新增 USB MIDI 1.0 CC 双向联动。

**Architecture:** 在现有两个 HID 接口之后追加 IAD + Audio Control + MIDI Streaming 接口。TX 使用 kfifo 环形缓冲区暂存 4 字节 MIDI Event Packet，由 SysTick 1ms 周期通过 Bulk IN EP4 发送。RX 在中断中 NAK 保留数据，主循环直接解析 USB DMA 缓冲区后 ACK。

**Tech Stack:** CH32V203C8T, USBFS, tpusb (USB 描述符生成), kfifo

---

## 文件结构

### 新增文件

| 文件 | 职责 |
|---|---|
| `User/usb/midi_cc.h` | MIDI CC 模块公共 API：初始化、发送、接收处理、常量、CC 映射表 |
| `User/usb/midi_cc.c` | MIDI CC 模块实现：TX FIFO 管理、Bulk 发送/接收逻辑、Event Packet 解析 |

### 修改文件

| 文件 | 改动 |
|---|---|
| `User/usb/usb_desc.cpp` | bcdUSB 0x0110→0x0200；追加 IAD + AC Interface + MIDI Streaming Interface 描述符 |
| `User/usb/usb_impl.h` | 新增 `kMidiEpAddr_In=0x84`, `kMidiEpAddr_Out=0x05` 常量 |
| `User/usb/usb_impl.c` | `UsbImpl_InitAndOpenEndpoints()` 配置 EP4/EP5；`UsbImpl_EpInComplete` 处理 EP4；`UsbImpl_EpOutComplete` 处理 EP5 |
| `User/bsp/ch32v20x_it.c` | `SysTick_Handler()` 追加 `MidiCC_Flush()` |
| `User/app/app.c` | `App_Init()` 调用 `MidiCC_Init()`；主循环调用 `MidiCC_ProcessRx()` |
| `User/app/motor.c` | `Motor_RunControlLoop()` 中 ADC 更新后调用 `MidiCC_CheckAndSend()`；电机停止时清除防回环标志 |

### 不变文件

`usb_device.c/h`, `usb_endpoint.h`, `usb_hardware.h`, `motor_hw.c/h`, `pid.c/h`

---

### Task 1: USB 描述符 — 修改 usb_desc.cpp

**Files:**
- Modify: `User/usb/usb_desc.cpp`

**说明：**
- 修改 `kDevice` 的 `bcdUSB` 从 `0x0110` 为 `0x0200`
- 在 `kConfig` 中两个 HID Interface 之后追加 IAD + Audio Control Interface + MIDI Streaming Interface
- 使用 tpusb 现有基础设施

- [ ] **Step 1: 修改 Device Descriptor 的 bcdUSB**

将：
```cpp
static constexpr auto kDevice =
tpusb::Device{
    0x0110,     // bcdUSB = 1.10
```
改为：
```cpp
static constexpr auto kDevice =
tpusb::Device{
    0x0200,     // bcdUSB = 2.00
```

- [ ] **Step 2: 添加 IAD + AC + MIDI Streaming 描述符到 kConfig**

在现有 `kConfig` 的第二个 HID Interface 闭括号之后、整个 `}` 结束之前，追加 IAD + AC Interface + MIDI Streaming Interface。

需要添加的 include（文件顶部已有 `#include "tpusb/device.hpp"` `#include "tpusb/hid.hpp"`，追加 `#include "tpusb/uac2.hpp"` 和 `#include "tpusb/midiv1.hpp"`）：

```cpp
#include "tpusb/uac2.hpp"
#include "tpusb/midiv1.hpp"
```

在 `kConfig` 的第二个 `tpusb::hid::HID_Interface{...}}` 之后添加：

```cpp
    ,
    /* IAD for Audio Control + MIDI Streaming */
    tpusb::InterfaceAssociation{
        tpusb::InterfaceAssociationInitPack{
            .function_class = 1,     // Audio
            .function_subclass = 3,  // MIDIStreaming
            .function_protocol = 0,
            .function_str_id = 0
        },
        /* Interface 2: Audio Control (空, 无端点) */
        tpusb::Interface{
            tpusb::InterfaceInitPack{
                .interface_no = 2,
                .alter = 0,
                .class_ = 1,         // Audio
                .subclass = 1,       // AudioControl
                .protocol = 0,
                .str_id = 0
            },
            tpusb::uac2::AudioFunction{
                tpusb::uac2::AudioFunctionInitPack{
                    .bcd_adc = 0x0200,
                    .catalog = tpusb::uac2::AudioFunctionCatalog::kOther,
                    .controls = 0x00
                }
            }
        },
        /* Interface 3: MIDI Streaming */
        tpusb::midiv1::MIDIStreamInterface{
            tpusb::InterfaceInitPackClassed{
                .interface_no = 3,
                .alter = 0,
                .protocol = 0,
                .str_id = 0
            },
            tpusb::midiv1::ExternalMidiInJack{1, 1},
            tpusb::midiv1::ExternalMidiOutJack{1, 1},
            tpusb::midiv1::MidiEndpoint<1>{
                tpusb::BulkInitPack{0x84, 64, 0},
                tpusb::midiv1::EndpointJackAssociation<1>{1}
            },
            tpusb::midiv1::MidiEndpoint<1>{
                tpusb::BulkInitPack{0x05, 64, 0},
                tpusb::midiv1::EndpointJackAssociation<1>{1}
            }
        }
    }
```

- [ ] **Step 3: 验证编译**

```bash
cmake --build build
```
Expected: 编译通过，无错误。

---

### Task 2: MIDI CC 模块头文件 — 创建 midi_cc.h

**Files:**
- Create: `User/usb/midi_cc.h`

- [ ] **Step 1: 创建 midi_cc.h**

```c
/**
 * @file    midi_cc.h
 * @brief   USB MIDI CC 双向联动 — 公共 API
 */
#pragma once

#include <stdbool.h>
#include <stdint.h>

/* 电机总数 (来自 motor.h 的 kMotorIdx_Count) */
#include "bsp/motor_hw.h"

// ------------------------------------------------------------
// 常量
// ------------------------------------------------------------

/** @brief MIDI Bulk IN 端点地址 */
#define kMidiEpAddr_In   0x84

/** @brief MIDI Bulk OUT 端点地址 */
#define kMidiEpAddr_Out  0x05

/** @brief MIDI Bulk 端点最大包大小 */
#define kMidiEpMpsize    64

/** @brief TX FIFO 大小 (字节), 必须为 2 的幂 */
#define MIDI_TX_FIFO_SIZE 128

/** @brief Code Index Number: Control Change */
#define MIDI_CIN_CC 0x0B

/** @brief MIDI 通道 1 (0-based) */
#define MIDI_DEFAULT_CHANNEL 0

// ------------------------------------------------------------
// CC 映射
// ------------------------------------------------------------

/**
 * @brief MIDI CC 映射条目
 */
struct MidiCcMapping {
    uint8_t channel;  /**< MIDI 通道 (0-based, 0=Channel 1) */
    uint8_t cc_num;   /**< CC 编号 (0~127) */
};

/**
 * @brief 默认 CC 映射表
 */
extern const struct MidiCcMapping kMidiCcMap[kMotorIdx_Count];

// ------------------------------------------------------------
// 公共 API
// ------------------------------------------------------------

/**
 * @brief 初始化 MIDI CC 模块
 */
void MidiCC_Init(void);

/**
 * @brief 发送 MIDI CC 消息 (阻塞式: FIFO 满则循环等待)
 * @param idx       电位器编号
 * @param cc_value  CC 值 (0~127)
 */
void MidiCC_Send(uint8_t idx, uint8_t cc_value);

/**
 * @brief 周期性 Flush: 将 TX FIFO 数据通过 Bulk IN 发送
 *        由 SysTick_Handler 和 EP4 IN Complete 调用
 */
void MidiCC_Flush(void);

/**
 * @brief 处理接收到的 MIDI 数据
 *        由 App_Loop 主循环调用
 */
void MidiCC_ProcessRx(void);

/**
 * @brief 检查并发送 CC (如需): 映射 ADC → CC, 去重, 防回环
 * @param idx     电位器编号
 * @param raw_adc 原始 ADC 值 (0~4095)
 */
void MidiCC_CheckAndSend(uint8_t idx, uint16_t raw_adc);

/**
 * @brief 设置防回环标志
 * @param idx    电位器编号
 * @param active true=正在响应 RX 驱动
 */
void MidiCC_SetRxActive(uint8_t idx, bool active);
```

---

### Task 3: MIDI CC 模块实现 — 创建 midi_cc.c

**Files:**
- Create: `User/usb/midi_cc.c`

- [ ] **Step 1: 创建 midi_cc.c — 静态变量和映射表**

```c
/**
 * @file    midi_cc.c
 * @brief   USB MIDI CC 双向联动 — 实现
 */
#include "midi_cc.h"

#include <string.h>

#include "config.h"
#include "usb/usb_device.h"
#include "usb/usb_hardware.h"
#include "usb/usb_impl.h"
#include "util/kfifo.h"

// ------------------------------------------------------------
// 静态变量
// ------------------------------------------------------------

/* TX FIFO */
static struct {
    struct Kfifo fifo;
    uint8_t buf[MIDI_TX_FIFO_SIZE];
} midi_tx_fifo_;

/* EP4 DMA 缓冲区 */
__attribute__((aligned(4))) static uint8_t midi_ep4_tx_buf_[kMidiEpMpsize];
static volatile bool midi_tx_busy_;
static bool midi_zlp_needed_;

/* EP5 DMA 缓冲区 */
__attribute__((aligned(4))) uint8_t midi_ep5_rx_buf_[kMidiEpMpsize];
volatile uint8_t midi_rx_pending_len_;

/* 上次发送的 CC 值 (去重) */
static uint8_t last_sent_cc_[kMotorIdx_Count];

/* 防回环标志 */
static bool fader_rx_active_[kMotorIdx_Count];

// ------------------------------------------------------------
// 默认 CC 映射表
// ------------------------------------------------------------

const struct MidiCcMapping kMidiCcMap[kMotorIdx_Count] = {
    {0, 0},   /* 电位器0 → Channel 1, CC 0  */
    {0, 1},   /* 电位器1 → Channel 1, CC 1  */
    {0, 2},   /* 电位器2 → Channel 1, CC 2  */
    {0, 3},   /* 电位器3 → Channel 1, CC 3  */
    {0, 4},   /* 电位器4 → Channel 1, CC 4  */
    {0, 5},   /* 电位器5 → Channel 1, CC 5  */
    {0, 6},   /* 电位器6 → Channel 1, CC 6  */
    {0, 7},   /* 电位器7 → Channel 1, CC 7  */
};
```

- [ ] **Step 2: 实现 MidiCC_Init**

```c
void MidiCC_Init(void) {
    midi_tx_fifo_.fifo.mask = MIDI_TX_FIFO_SIZE - 1;
    midi_tx_fifo_.fifo.wpos = 0;
    midi_tx_fifo_.fifo.rpos = 0;
    midi_tx_busy_ = false;
    midi_zlp_needed_ = false;
    midi_rx_pending_len_ = 0;
    for (int i = 0; i < kMotorIdx_Count; i++) {
        last_sent_cc_[i] = 0xFF;  /* 初始化为无效值，确保首次发送 */
        fader_rx_active_[i] = false;
    }
}
```

- [ ] **Step 3: 实现 MidiCC_Send (阻塞式入队)**

```c
void MidiCC_Send(uint8_t idx, uint8_t cc_value) {
    if (!HID_IsConnected())
        return;

    /* 构造 4 字节 USB MIDI Event Packet */
    uint8_t packet[4];
    packet[0] = MIDI_CIN_CC;                                    /* CIN=0x0B, Cable=0 */
    packet[1] = (uint8_t)(0xB0 | kMidiCcMap[idx].channel);      /* Status: CC + Channel */
    packet[2] = kMidiCcMap[idx].cc_num;                         /* CC 编号 */
    packet[3] = cc_value;                                        /* CC 值 */

    /* 循环等待 FIFO 空间 (由 SysTick 中断消费腾空) */
    while (Kfifo_FreeSpace(&midi_tx_fifo_.fifo) < 4) {
        /* SysTick_Handler 中的 MidiCC_Flush() 会在此期间响应 */
    }
    Kfifo_TryPush(&midi_tx_fifo_.fifo, packet, 4);
}
```

- [ ] **Step 4: 实现 MidiCC_Flush (含 ZLP 处理)**

```c
void MidiCC_Flush(void) {
    if (midi_tx_busy_)
        return;

    uint32_t available = Kfifo_Size(&midi_tx_fifo_.fifo);

    if (available == 0) {
        /* FIFO 空: 检查是否需要发送 ZLP */
        if (midi_zlp_needed_) {
            midi_zlp_needed_ = false;
            USBFSD->UEP4_TX_LEN = 0;
            midi_tx_busy_ = true;
            USBFSD->UEP4_TX_CTRL = (USBFSD->UEP4_TX_CTRL & ~USBFS_UEP_T_RES_MASK) | USBFS_UEP_T_RES_ACK;
        }
        return;
    }

    uint32_t to_read = (available > kMidiEpMpsize) ? kMidiEpMpsize : available;
    uint32_t total = 0;

    /* 从 kfifo 读取 (可能跨越环形缓冲区边界) */
    while (total < to_read) {
        uint32_t chunk;
        uint8_t* src = Kfifo_ContinueReadBegin(&midi_tx_fifo_.fifo, &chunk);
        uint32_t need = to_read - total;
        if (chunk > need)
            chunk = need;
        if (chunk == 0)
            break;
        memcpy(midi_ep4_tx_buf_ + total, src, chunk);
        Kfifo_ContinueReadEnd(&midi_tx_fifo_.fifo, chunk);
        total += chunk;
    }

    midi_zlp_needed_ = (total == kMidiEpMpsize);
    midi_tx_busy_ = true;

    USBFSD->UEP4_TX_LEN = total;
    USBFSD->UEP4_TX_CTRL = (USBFSD->UEP4_TX_CTRL & ~USBFS_UEP_T_RES_MASK) | USBFS_UEP_T_RES_ACK;
}
```

- [ ] **Step 5: 实现 MidiCC_ProcessRx**

```c
void MidiCC_ProcessRx(void) {
    if (midi_rx_pending_len_ == 0)
        return;

    /* 直接解析 USB DMA 缓冲区中的 Event Packet */
    uint8_t len = midi_rx_pending_len_;
    for (uint8_t offset = 0; offset + 3 < len; offset += 4) {
        uint8_t status = midi_ep5_rx_buf_[offset + 1];

        /* 仅处理 Control Change 消息 */
        if ((status & 0xF0) != 0xB0)
            continue;

        uint8_t channel = status & 0x0F;
        uint8_t cc_num  = midi_ep5_rx_buf_[offset + 2];
        uint8_t cc_val  = midi_ep5_rx_buf_[offset + 3];

        /* 查映射表 */
        for (uint8_t i = 0; i < kMotorIdx_Count; i++) {
            if (kMidiCcMap[i].channel == channel && kMidiCcMap[i].cc_num == cc_num) {
                /* 反向映射: [0,127] → [0,4095] */
                uint16_t target_pos = (uint16_t)((uint32_t)cc_val * 4095 / 127);
                fader_rx_active_[i] = true;
                Motor_SetTarget(i, target_pos);
                break;
            }
        }
    }

    /* 全部消耗, ACK EP5 */
    midi_rx_pending_len_ = 0;
    USBFSD->UEP5_RX_CTRL = (USBFSD->UEP5_RX_CTRL & ~USBFS_UEP_R_RES_MASK) | USBFS_UEP_R_RES_ACK;
}
```

- [ ] **Step 6: 实现 MidiCC_CheckAndSend 和防回环接口**

```c
void MidiCC_CheckAndSend(uint8_t idx, uint16_t raw_adc) {
    if (idx >= kMotorIdx_Count)
        return;

    /* 防回环: RX 驱动中的通道不发送 TX */
    if (fader_rx_active_[idx])
        return;

    /* 映射 ADC 到 CC 值 [0,127] */
    uint8_t cc_value = (uint8_t)((uint32_t)raw_adc * 127 / 4095);

    /* 去重: 与上次发送值相同则跳过 */
    if (cc_value == last_sent_cc_[idx])
        return;

    last_sent_cc_[idx] = cc_value;
    MidiCC_Send(idx, cc_value);
}

void MidiCC_SetRxActive(uint8_t idx, bool active) {
    if (idx < kMotorIdx_Count)
        fader_rx_active_[idx] = active;
}
```

---

### Task 4: USB IMPL — 端点配置与中断处理

**Files:**
- Modify: `User/usb/usb_impl.h`
- Modify: `User/usb/usb_impl.c`

- [ ] **Step 1: usb_impl.h — 声明 EP4/EP5 常量**

在 `usb_impl.h` 的文件末尾或适当位置，添加 EP4/EP5 的声明。注意 `kMidiEpAddr_In` 和 `kMidiEpAddr_Out` 已在 `midi_cc.h` 中定义，但 `usb_impl.h` 需要知道端点模式配置用的常量。

实际不需要在 `usb_impl.h` 添加额外内容，因为 MIDI 端点配置将在 `UsbImpl_InitAndOpenEndpoints()` 中通过直接写寄存器完成。

- [ ] **Step 2: usb_impl.c — 修改 UsbImpl_InitAndOpenEndpoints()**

追加 EP4/EP5 的初始化：

```c
    /* EP4: MIDI Bulk IN (TX) */
    USBFSD->UEP4_1_MOD |= USBFS_UEP4_TX_EN;
    USBFSD->UEP4_DMA = (uint32_t)midi_ep4_tx_buf_;
    USBFSD->UEP4_TX_LEN = 0;
    USBFSD->UEP4_TX_CTRL = USBFS_UEP_T_RES_NAK;

    /* EP5: MIDI Bulk OUT (RX) */
    USBFSD->UEP5_6_MOD |= USBFS_UEP5_RX_EN;
    USBFSD->UEP5_DMA = (uint32_t)midi_ep5_rx_buf_;
    USBFSD->UEP5_RX_CTRL = USBFS_UEP_R_RES_ACK;

    /* 初始化 MIDI CC 模块 */
    MidiCC_Init();
```

注意：需要在文件顶部添加 `#include "usb/midi_cc.h"`。

- [ ] **Step 3: usb_impl.c — 修改 UsbImpl_EpInComplete**

在 EP2 的 case 之后添加 EP4 处理：

```c
        case kMidiEpAddr_In & 0xf:
            midi_tx_busy_ = false;
            USBFSD->UEP4_TX_CTRL ^= USBFS_UEP_T_TOG;
            USBFSD->UEP4_TX_CTRL = (USBFSD->UEP4_TX_CTRL & ~USBFS_UEP_T_RES_MASK) | USBFS_UEP_T_RES_NAK;
            MidiCC_Flush();
            break;
```

- [ ] **Step 4: usb_impl.c — 修改 UsbImpl_EpOutComplete**

在 EP3 的 case 之后添加 EP5 处理：

```c
        case kMidiEpAddr_Out & 0xf:
            if (midi_rx_pending_len_ == 0) {
                uint16_t rx_count = USBFSD->RX_LEN;
                if (rx_count > kMidiEpMpsize)
                    rx_count = kMidiEpMpsize;
                if (rx_count == 0) {
                    /* ZLP: 直接 ACK */
                    USBFSD->UEP5_RX_CTRL = (USBFSD->UEP5_RX_CTRL & ~USBFS_UEP_R_RES_MASK) | USBFS_UEP_R_RES_ACK;
                } else {
                    midi_rx_pending_len_ = (uint8_t)rx_count;
                    USBFSD->UEP5_RX_CTRL = (USBFSD->UEP5_RX_CTRL & ~USBFS_UEP_R_RES_MASK) | USBFS_UEP_R_RES_NAK;
                }
            }
            break;
```

`midi_ep5_rx_buf_` 和 `midi_rx_pending_len_` 需要在 `usb_impl.c` 中声明为外部变量或在 `midi_cc.c` 中定义为非 static。方案：在 `midi_cc.c` 中将这两个变量改为非 static（去掉 static），并在 `midi_cc.h` 中声明为 extern。

在 `midi_cc.h` 中添加：
```c
/* USB DMA 缓冲区 (供 usb_impl.c 中断处理访问) */
extern __attribute__((aligned(4))) uint8_t midi_ep5_rx_buf_[kMidiEpMpsize];
extern volatile uint8_t midi_rx_pending_len_;
```

- [ ] **Step 5: 验证编译**

```bash
cmake --build build
```
Expected: 编译通过。

---

### Task 5: SysTick 集成 — 修改 ch32v20x_it.c

**Files:**
- Modify: `User/bsp/ch32v20x_it.c`

- [ ] **Step 1: 在 SysTick_Handler 中添加 MidiCC_Flush()**

```c
#include "usb/midi_cc.h"

void SysTick_Handler(void) {
    SysTick->SR = 0;
    Tick_Increment();
    HID_Flush();
    MidiCC_Flush();    /* 新增: MIDI TX Flush */
}
```

---

### Task 6: App 层集成 — 修改 app.c

**Files:**
- Modify: `User/app/app.c`

- [ ] **Step 1: 在 App_Init 和 App_Loop 中集成 MIDI CC**

```c
#include "usb/midi_cc.h"

void App_Init(void) {
    Motor_InitControl();
    MidiCC_Init();
}

void App_Loop(void) {
    while (1) {
        /* ── 1kHz 控制状态机 ── */
        switch (ctrl_state_) {
            case kCtrlState_Idle:
                if (Tick_Get() != last_ctrl_tick_) {
                    last_ctrl_tick_ = Tick_Get();
                    ctrl_state_ = kCtrlState_AdcStart;
                }
                break;
            case kCtrlState_AdcStart:
                Motor_StartAdcConversion();
                ctrl_state_ = kCtrlState_AdcWait;
                break;
            case kCtrlState_AdcWait:
                if (Motor_IsAdcReady()) {
                    ctrl_state_ = kCtrlState_Control;
                }
                break;
            case kCtrlState_Control:
                Motor_RunControlLoop();
                ctrl_state_ = kCtrlState_Idle;
                break;
        }

        Motor_SendStatus();
        Motor_ProcessCommand();
        MidiCC_ProcessRx();    /* 新增: 处理接收到的 MIDI CC */
    }
}
```

---

### Task 7: 电机控制集成 — 修改 motor.c

**Files:**
- Modify: `User/app/motor.c`

- [ ] **Step 1: 包含 midi_cc.h**

```c
#include "usb/midi_cc.h"
```

- [ ] **Step 2: 在 Motor_RunControlLoop 中添加 CC 发送和防回环清除**

在 `Motor_RunControlLoop` 中，每路电机处理完成后（PWM 设置之后或 active 变为 false 时），添加：

在 `if (!motor_states_[i].active_)` 分支中，跳过后续处理；但我们需要在 ADC 更新后、active 检查之前调用 CC 检查。修改后的循环体：

```c
for (int i = 0; i < kMotorIdx_Count; i++) {
    motor_states_[i].current_adc_ = raw_adc[i];

    /* MIDI CC 检查 (防回环: 会自动跳过 fader_rx_active_ 的通道) */
    MidiCC_CheckAndSend(i, raw_adc[i]);

    /* 非活跃电机：跳过，PWM 保持 0 */
    if (!motor_states_[i].active_)
        continue;

    /* ... 原有停止/超时/PID逻辑 ... */

    /* 到达目标或超时停止后, 清除防回环标志 */
    if (!motor_states_[i].active_) {
        MidiCC_SetRxActive(i, false);
    }
}
```

注意：需要在 `Motor_RunControlLoop` 中现有的 `if (!motor_states_[i].active_) continue;` 之前添加 `MidiCC_CheckAndSend(i, raw_adc[i]);`。

并且在每路 `active_` 从 true→false 的位置（到达目标停止处和超时停止处）清除防回环标志。

---

### Task 8: 最终验证

- [ ] **Step 1: 完整编译**

```bash
cmake --build build
```
Expected: 编译通过，无警告。

- [ ] **Step 2: 检查二进制大小**

确认固件大小在合理范围内（不应显著增加，MIDI 功能代码量很小）。

- [ ] **Step 3: 代码审查**

确认所有改动符合 `AGENTS.md` 中的编码约定：
- 全局变量以 `_` 结尾 ✓ (`midi_ep5_rx_buf_`, `midi_rx_pending_len_`)
- 头文件函数声明 `模块_动作` 格式 ✓ (`MidiCC_Init`, `MidiCC_Send`, `MidiCC_Flush`)
- 枚举值前缀 `k` ✓ (`kMidiEpAddr_In`, `kMidiEpAddr_Out`, `kMidiCcMap`, `MIDI_CIN_CC`)
- 无 `extern` 全局变量替代方案：`midi_ep5_rx_buf_` 和 `midi_rx_pending_len_` 在 `midi_cc.c` 中定义，`midi_cc.h` 中 `extern` 声明供 `usb_impl.c` 访问
- 无 typedef 对结构体/枚举

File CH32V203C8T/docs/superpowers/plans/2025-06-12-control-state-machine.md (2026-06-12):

# 控制流水线状态机 + HID 数据分离 实现计划

> **日期:** 2025-06-12
> **关联文档:** `2025-06-12-motor-control.md`（原始硬件驱动实现）

---

## 目标

将当前控制流水线改为**状态机驱动**，实现：
1. ADC 启动/电机控制/HID 上报由状态机管理
2. 1kHz 固定执行频率
3. HID 命令处理和 HID0 刷新保留在原位置（不混入状态机）

---

## 当前架构（改造前）

```
SysTick ISR (1ms):
  Tick_Increment()
  Motor_StartAdcConversion()     ← ADC 在 ISR 中触发
  HID_Flush()                    ← HID0 printf 刷新（保持原位）

DMA ISR:
  motor_adc_ready_ = true

Main loop:
  if (Motor_IsAdcReady())
    Motor_RunControlLoop()       ← 包含 PID + PWM + HID1_SendStatus
  HID1_ProcessCommand()          ← HID1 命令处理（保持原位）
```

## 目标架构

```
SysTick ISR (1ms):
  Tick_Increment()
  HID_Flush()                    ← ※ 原位保留，仅移除 ADC 启动

Main loop ── 状态机:
                     Tick 变化
    IDLE ──────────────────────────→ ADC_START
     ↑                                   │
     │                              Motor_StartAdcConversion()
     │                                   ↓
     │                              ADC_WAIT ← 轮询 motor_adc_ready_
     │                                   │
     │                              ADC 就绪
     │                                   ↓
     │                              CONTROL
     │                                Motor_RunControlLoop()  ① 纯 PID+PWM
     │                                HID1_SendStatus(...)    ② 写 HID 状态
     │                                   │
     └──────────── 回到 IDLE ────────────┘

  HID1_ProcessCommand()          ← ※ 原位保留，每次主循环迭代执行
```

---

## 状态定义

```
enum CtrlState {
    kCtrlState_Idle,       // 等待 1ms tick 到达
    kCtrlState_AdcStart,   // 触发 ADC 转换
    kCtrlState_AdcWait,    // 等待 ADC+DMA 完成
    kCtrlState_Control,    // 电机 PID → PWM → HID 状态上报
};
```

### 各状态行为

| 状态 | 触发 | 执行动作 | 下一状态 |
|---|---|---|---|
| `IDLE` | 每次迭代 | 检查 `Tick_Get()` 是否变化 | 变化 → `ADC_START` |
| `ADC_START` | 单次 | `Motor_StartAdcConversion()` | → `ADC_WAIT` |
| `ADC_WAIT` | 每次迭代 | 检查 `Motor_IsAdcReady()` | true → `CONTROL` |
| `CONTROL` | 单次 | `Motor_RunControlLoop()` + `HID1_SendStatus()` | → `IDLE` |

### 时序

```
Tick n       Tick n+1
  │              │
  ▼              ▼
IDLE→ADC→WAIT→CTRL→IDLE→ADC→WAIT→CTRL→...
  │<── ~14μs ──>│
  │<── ~1ms ───────>│
```

- `ADC_START` → `CONTROL` 耗时约 14~50μs
- 其余大部分时间落在 `IDLE` 状态等待下一 tick

---

## 涉及改动

### 1. `ch32v20x_it.c` — SysTick_Handler

```c
void SysTick_Handler(void)
{
    SysTick->SR = 0;
    Tick_Increment();
    // Motor_StartAdcConversion();  ← 移除，由状态机触发
    HID_Flush();                     // ← 保持原位
}
```

### 2. `motor.h` / `motor.c` — 拆分职责

**Motor_RunControlLoop()** 末尾移除 HID1_SendStatus 块：

```c
void Motor_RunControlLoop(void)
{
    if (!motor_adc_ready_) return;

    for (int i = 0; i < MOTOR_COUNT; i++) {
        motor_states_[i].current_adc_ = motor_adc_dma_buf_[i];
        // ... PID 计算 ...
        Motor_SetPwm(i, motor_states_[i].dir_, motor_states_[i].duty_);
    }

    // ※ HID1_SendStatus 调用已移出，由 main 中的状态机调用
}
```

新增 `Motor_GetStatus()` 供 main 调用 HID1_SendStatus 时获取数据：

```c
// motor.h 声明:
void Motor_GetStatus(uint16_t adc[8], uint16_t target[8], uint16_t duty[8]);

// motor.c 实现:
void Motor_GetStatus(uint16_t adc[8], uint16_t target[8], uint16_t duty[8])
{
    for (int i = 0; i < MOTOR_COUNT; i++) {
        adc[i]    = motor_states_[i].current_adc_;
        target[i] = motor_states_[i].target_adc_;
        duty[i]   = motor_states_[i].duty_;
    }
}
```

### 3. `main.c` — 状态机 + 保留原位调用

```c
#include "motor.h"
#include "usb/usb_impl.h"
// ...

enum CtrlState {
    kCtrlState_Idle,
    kCtrlState_AdcStart,
    kCtrlState_AdcWait,
    kCtrlState_Control,
};

static enum CtrlState ctrl_state_ = kCtrlState_Idle;
static uint32_t last_ctrl_tick_ = 0;

int main(void)
{
    // ... 初始化（不变）...

    while (1)
    {
        /* ── 控制状态机（1kHz） ── */
        switch (ctrl_state_) {
        case kCtrlState_Idle:
            if (Tick_Get() != last_ctrl_tick_) {
                last_ctrl_tick_ = Tick_Get();
                ctrl_state_ = kCtrlState_AdcStart;
            }
            break;

        case kCtrlState_AdcStart:
            Motor_StartAdcConversion();
            ctrl_state_ = kCtrlState_AdcWait;
            break;

        case kCtrlState_AdcWait:
            if (Motor_IsAdcReady()) {
                ctrl_state_ = kCtrlState_Control;
            }
            /* 非忙等待，每次主循环只检查一次 */
            break;

        case kCtrlState_Control:
            Motor_RunControlLoop();          // ① PID → PWM
            {
                uint16_t adc[8], target[8], duty[8];
                Motor_GetStatus(adc, target, duty);
                HID1_SendStatus(adc, target, duty);  // ② HID 数据写
            }
            ctrl_state_ = kCtrlState_Idle;
            break;
        }

        /* ── HID1 命令处理（保持原位，每次迭代执行） ── */
        HID1_ProcessCommand();
    }
}
```

---

## 关键注意事项

### 1. ADC_WAIT 非忙等待

`ADC_WAIT` 状态下**不阻塞**，每次主循环只检查一次 `Motor_IsAdcReady()` 就回到 switch 出口。
ADC 转换期间（~14μs）主循环可以立即进入下一迭代处理 `HID1_ProcessCommand()`。

### 2. HID TX DMA vs RX DMA

- **TX DMA**（EP2 IN）：硬件**读取**缓冲区 → CPU 可以随时安全更新 `hid1_report_buf_`
- **RX DMA**（EP2 OUT）：硬件**写入**缓冲区 → 需在 OUT 完成中断后读取

当前 `HID1_SendStatus()` 只写缓冲区、不操作 DMA 寄存器，
与状态机解耦后也无需额外保护。

### 3. 控制周期

状态机由 `Tick_Get()` 变化驱动，保证 **1kHz 固定频率**。
即使 `ADC_WAIT` 偶尔跨 tick，状态机也只在 tick 边界触发下一轮。

### 4. HID1_SendStatus 数据来源

`Motor_GetStatus()` 在 `Motor_RunControlLoop()` 之后调用，
此时 `motor_states_[i]` 已包含最新的 ADC/Target/Duty 值。

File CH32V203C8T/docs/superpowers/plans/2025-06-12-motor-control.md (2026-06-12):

# 八路电机控制 + HID1 接口 实现计划

> **For agentic workers:** REQUIRED SUB-SKILL: Use superpowers:subagent-driven-development (recommended) or superpowers:executing-plans to implement this plan task-by-task. Steps use checkbox (`- [ ]`) syntax for tracking.

**Goal:** 实现 8 路电机闭环位置控制（AD→PID→PWM），并通过独立的 USB HID1 接口通信。

**Architecture:** SysTick @1kHz 触发 ADC 注入组扫描 → ADC 完成中断执行 8 路 PID → 更新 PWM 比较值。HID1 在主循环中处理命令/状态。

**Tech Stack:** CH32V203C8T, USBFS, ch32v20x 标准外设库

---

### Task 1: PWM 定时器配置

**Files:**
- Create: `User/motor.h`
- Create: `User/motor.c`

**说明：**
- TIM1~TIM4 全部配置为 PWM 输出，ARR=999，边沿对齐向上计数，预分频 = 0
- 定时器时钟 = 96MHz，PWM 频率 = 96kHz
- Motor 3 使用 GPIO PB14/PB15 软件控制

- [ ] **Step 1: 创建 motor.h，声明 PWM 和 GPIO 初始化接口**

```c
#pragma once
#include <stdint.h>
#include <stdbool.h>

/* 电机总数 */
#define MOTOR_COUNT 8

/* 电机通道 (0-based index, 对应 ADC 通道) */
#define MOTOR_1  0
#define MOTOR_2  1
#define MOTOR_3  2
#define MOTOR_4  3
#define MOTOR_5  4
#define MOTOR_6  5
#define MOTOR_7  6
#define MOTOR_8  7

/* 方向 */
typedef enum {
    kMotorDir_Stop   = 0,  /* IN1=0, IN2=0 (coast) */
    kMotorDir_Forward,     /* IN1=PWM, IN2=0 */
    kMotorDir_Reverse,     /* IN1=0, IN2=PWM */
    kMotorDir_Brake,       /* IN1=1, IN2=1 */
} MotorDir;

void Motor_InitPwm(void);
void Motor_SetPwm(uint8_t ch, MotorDir dir, uint16_t duty);
```

- [ ] **Step 2: 实现 motor.c 中的 TIM1 初始化**

配置 TIM1 CH1~CH4（对应电机 4/5）：
```c
#include "motor.h"
#include "ch32v20x.h"
#include "ch32v20x_tim.h"
#include "ch32v20x_gpio.h"
#include "ch32v20x_rcc.h"

void Motor_InitPwm(void)
{
    GPIO_InitTypeDef gpio;
    TIM_TimeBaseInitTypeDef tim;
    TIM_OCInitTypeDef oc;

    /* === TIM1: 电机 4 (CH2/CH1), 电机 5 (CH3/CH4) === */
    RCC_APB2PeriphClockCmd(RCC_APB2Periph_TIM1 | RCC_APB2Periph_GPIOA
                           | RCC_APB2Periph_GPIOB, ENABLE);

    /* TIM1 CH1=PA8, CH2=PA9, CH3=PA10, CH4=PA11 */
    gpio.GPIO_Pin = GPIO_Pin_8 | GPIO_Pin_9 | GPIO_Pin_10 | GPIO_Pin_11;
    gpio.GPIO_Mode = GPIO_Mode_AF_PP;
    gpio.GPIO_Speed = GPIO_Speed_50MHz;
    GPIO_Init(GPIOA, &gpio);

    TIM_TimeBaseStructInit(&tim);
    tim.TIM_Prescaler = 0;
    tim.TIM_CounterMode = TIM_CounterMode_Up;
    tim.TIM_Period = 999;        /* 1000 steps → 96kHz */
    tim.TIM_ClockDivision = 0;
    TIM_TimeBaseInit(TIM1, &tim);

    TIM_OCStructInit(&oc);
    oc.TIM_OCMode = TIM_OCMode_PWM1;
    oc.TIM_OutputState = TIM_OutputState_Enable;
    oc.TIM_Pulse = 0;
    oc.TIM_OCPolarity = TIM_OCPolarity_High;

    oc.TIM_OCIdleState = TIM_OCIdleState_Reset;
    oc.TIM_OCNIdleState = TIM_OCNIdleState_Reset;

    /* CH1 (电机5 B) */
    TIM_OC1Init(TIM1, &oc);
    /* CH2 (电机4 A) */
    oc.TIM_Pulse = 0;
    TIM_OC2Init(TIM1, &oc);
    /* CH3 (电机5 A) */
    oc.TIM_Pulse = 0;
    TIM_OC3Init(TIM1, &oc);
    /* CH4 (电机5 B) — 注意 PA11 同时也是 USB DM */
    oc.TIM_Pulse = 0;
    TIM_OC4Init(TIM1, &oc);

    /* 高级定时器需要使能 MOE 主输出 */
    TIM_CtrlPWMOutputs(TIM1, ENABLE);
    TIM_Cmd(TIM1, ENABLE);

    /* 后续继续初始化 TIM2, TIM3, TIM4... */
}
```

- [ ] **Step 3: 继续实现 TIM2 初始化（电机 2 + 电机 6）**

```c
    /* === TIM2: 电机 6 (CH1=PA15, CH2=PB3), 电机 2 (CH3=PB10, CH4=PB11) === */
    RCC_APB1PeriphClockCmd(RCC_APB1Periph_TIM2, ENABLE);
    RCC_APB2PeriphClockCmd(RCC_APB2Periph_GPIOA | RCC_APB2Periph_GPIOB, ENABLE);

    /* AFIO 重映射: TIM2_CH1 → PA15, TIM2_CH2 → PB3 */
    GPIO_PinRemapConfig(GPIO_PartialRemap1_TIM2, ENABLE);

    gpio.GPIO_Pin = GPIO_Pin_15;
    gpio.GPIO_Mode = GPIO_Mode_AF_PP;
    GPIO_Init(GPIOA, &gpio);

    gpio.GPIO_Pin = GPIO_Pin_3 | GPIO_Pin_10 | GPIO_Pin_11;
    GPIO_Init(GPIOB, &gpio);

    TIM_TimeBaseStructInit(&tim);
    tim.TIM_Prescaler = 0;
    tim.TIM_CounterMode = TIM_CounterMode_Up;
    tim.TIM_Period = 999;
    tim.TIM_ClockDivision = 0;
    TIM_TimeBaseInit(TIM2, &tim);

    TIM_OCStructInit(&oc);
    oc.TIM_OCMode = TIM_OCMode_PWM1;
    oc.TIM_OutputState = TIM_OutputState_Enable;
    oc.TIM_Pulse = 0;
    oc.TIM_OCPolarity = TIM_OCPolarity_High;

    TIM_OC1Init(TIM2, &oc);  /* PA15 — 电机6 A? */
    /* 核对：定时器引脚表 PB3=电机6 A, PA15=电机6 B */
    oc.TIM_Pulse = 0;
    TIM_OC2Init(TIM2, &oc);  /* PB3 — 电机6 B? */
    oc.TIM_Pulse = 0;
    TIM_OC3Init(TIM2, &oc);  /* PB10 — 电机2 B */
    oc.TIM_Pulse = 0;
    TIM_OC4Init(TIM2, &oc);  /* PB11 — 电机2 A */

    TIM_Cmd(TIM2, ENABLE);
```

- [ ] **Step 4: 实现 TIM3 初始化（电机 1 + 电机 7）**

```c
    /* === TIM3: 电机 7 (CH1=PB4, CH2=PB5), 电机 1 (CH3=PB0, CH4=PB1) === */
    RCC_APB1PeriphClockCmd(RCC_APB1Periph_TIM3, ENABLE);
    /* GPIOB 已使能 */

    gpio.GPIO_Pin = GPIO_Pin_0 | GPIO_Pin_1 | GPIO_Pin_4 | GPIO_Pin_5;
    gpio.GPIO_Mode = GPIO_Mode_AF_PP;
    GPIO_Init(GPIOB, &gpio);

    TIM_TimeBaseStructInit(&tim);
    tim.TIM_Prescaler = 0;
    tim.TIM_CounterMode = TIM_CounterMode_Up;
    tim.TIM_Period = 999;
    tim.TIM_ClockDivision = 0;
    TIM_TimeBaseInit(TIM3, &tim);

    TIM_OCStructInit(&oc);
    oc.TIM_OCMode = TIM_OCMode_PWM1;
    oc.TIM_OutputState = TIM_OutputState_Enable;
    oc.TIM_Pulse = 0;
    oc.TIM_OCPolarity = TIM_OCPolarity_High;

    TIM_OC1Init(TIM3, &oc);  /* PB4 — 电机7 A */
    oc.TIM_Pulse = 0;
    TIM_OC2Init(TIM3, &oc);  /* PB5 — 电机7 B */
    oc.TIM_Pulse = 0;
    TIM_OC3Init(TIM3, &oc);  /* PB0 — 电机1 A */
    oc.TIM_Pulse = 0;
    TIM_OC4Init(TIM3, &oc);  /* PB1 — 电机1 B */

    TIM_Cmd(TIM3, ENABLE);
```

- [ ] **Step 5: 实现 TIM4 初始化（电机 8）和 Motor 3 GPIO**

```c
    /* === TIM4: 电机 8 (CH3=PB8, CH4=PB9) === */
    RCC_APB1PeriphClockCmd(RCC_APB1Periph_TIM4, ENABLE);

    gpio.GPIO_Pin = GPIO_Pin_8 | GPIO_Pin_9;
    gpio.GPIO_Mode = GPIO_Mode_AF_PP;
    GPIO_Init(GPIOB, &gpio);

    TIM_TimeBaseStructInit(&tim);
    tim.TIM_Prescaler = 0;
    tim.TIM_CounterMode = TIM_CounterMode_Up;
    tim.TIM_Period = 999;
    tim.TIM_ClockDivision = 0;
    TIM_TimeBaseInit(TIM4, &tim);

    TIM_OCStructInit(&oc);
    oc.TIM_OCMode = TIM_OCMode_PWM1;
    oc.TIM_OutputState = TIM_OutputState_Enable;
    oc.TIM_Pulse = 0;
    oc.TIM_OCPolarity = TIM_OCPolarity_High;

    TIM_OC3Init(TIM4, &oc);  /* PB8 — 电机8 A */
    oc.TIM_Pulse = 0;
    TIM_OC4Init(TIM4, &oc);  /* PB9 — 电机8 B */

    TIM_Cmd(TIM4, ENABLE);

    /* === 电机 3: GPIO PB14, PB15 === */
    RCC_APB2PeriphClockCmd(RCC_APB2Periph_GPIOB, ENABLE);
    gpio.GPIO_Pin = GPIO_Pin_14 | GPIO_Pin_15;
    gpio.GPIO_Mode = GPIO_Mode_Out_PP;
    gpio.GPIO_Speed = GPIO_Speed_50MHz;
    GPIO_Init(GPIOB, &gpio);
    GPIO_ResetBits(GPIOB, GPIO_Pin_14 | GPIO_Pin_15);
}
```

- [ ] **Step 6: 实现 Motor_SetPwm 函数**

```c
void Motor_SetPwm(uint8_t ch, MotorDir dir, uint16_t duty)
{
    if (duty > 999) duty = 999;

    if (ch == MOTOR_3) {
        /* GPIO 电机：IO 翻转 */
        if (dir == kMotorDir_Forward) {
            GPIO_SetBits(GPIOB, GPIO_Pin_14);
            GPIO_ResetBits(GPIOB, GPIO_Pin_15);
        } else if (dir == kMotorDir_Reverse) {
            GPIO_ResetBits(GPIOB, GPIO_Pin_14);
            GPIO_SetBits(GPIOB, GPIO_Pin_15);
        } else if (dir == kMotorDir_Brake) {
            GPIO_SetBits(GPIOB, GPIO_Pin_14 | GPIO_Pin_15);
        } else {
            GPIO_ResetBits(GPIOB, GPIO_Pin_14 | GPIO_Pin_15);
        }
        return;
    }

    /* 查表找到对应定时器+通道 */
    /* 电机 1: TIM3 CH3 (A=IN1), CH4 (B=IN2) */
    /* 电机 2: TIM2 CH4 (A), CH3 (B) */
    /* 电机 4: TIM1 CH2 (A), CH1 (B) */
    /* 电机 5: TIM1 CH3 (A), CH4 (B) */
    /* 电机 6: TIM2 CH1 (A), CH2 (B) */
    /* 电机 7: TIM3 CH1 (A), CH2 (B) */
    /* 电机 8: TIM4 CH3 (A), CH4 (B) */

    /* 使用 switch 或查表数组 */
    switch (ch) {
        case MOTOR_1: /* TIM3 CH3=A, CH4=B */
            TIM_SetCompare3(TIM3, (dir == kMotorDir_Forward || dir == kMotorDir_Brake) ? duty : 0);
            TIM_SetCompare4(TIM3, (dir == kMotorDir_Reverse || dir == kMotorDir_Brake) ? duty : 0);
            break;
        case MOTOR_2: /* TIM2 CH4=A, CH3=B */
            TIM_SetCompare4(TIM2, (dir == kMotorDir_Forward || dir == kMotorDir_Brake) ? duty : 0);
            TIM_SetCompare3(TIM2, (dir == kMotorDir_Reverse || dir == kMotorDir_Brake) ? duty : 0);
            break;
        case MOTOR_4: /* TIM1 CH2=A, CH1=B */
            TIM_SetCompare2(TIM1, (dir == kMotorDir_Forward || dir == kMotorDir_Brake) ? duty : 0);
            TIM_SetCompare1(TIM1, (dir == kMotorDir_Reverse || dir == kMotorDir_Brake) ? duty : 0);
            break;
        case MOTOR_5: /* TIM1 CH3=A, CH4=B */
            TIM_SetCompare3(TIM1, (dir == kMotorDir_Forward || dir == kMotorDir_Brake) ? duty : 0);
            TIM_SetCompare4(TIM1, (dir == kMotorDir_Reverse || dir == kMotorDir_Brake) ? duty : 0);
            break;
        case MOTOR_6: /* TIM2 CH1=A, CH2=B */
            TIM_SetCompare1(TIM2, (dir == kMotorDir_Forward || dir == kMotorDir_Brake) ? duty : 0);
            TIM_SetCompare2(TIM2, (dir == kMotorDir_Reverse || dir == kMotorDir_Brake) ? duty : 0);
            break;
        case MOTOR_7: /* TIM3 CH1=A, CH2=B */
            TIM_SetCompare1(TIM3, (dir == kMotorDir_Forward || dir == kMotorDir_Brake) ? duty : 0);
            TIM_SetCompare2(TIM3, (dir == kMotorDir_Reverse || dir == kMotorDir_Brake) ? duty : 0);
            break;
        case MOTOR_8: /* TIM4 CH3=A, CH4=B */
            TIM_SetCompare3(TIM4, (dir == kMotorDir_Forward || dir == kMotorDir_Brake) ? duty : 0);
            TIM_SetCompare4(TIM4, (dir == kMotorDir_Reverse || dir == kMotorDir_Brake) ? duty : 0);
            break;
    }
}
```

---

### Task 2: ADC + DMA 配置

**Files:**
- Modify: `User/motor.h` (添加 ADC/DMA 接口声明)
- Modify: `User/motor.c` (添加 ADC + DMA 初始化)

**说明：**
- ADC 常规组 scan 模式，8 通道（PA0~PA7），软件触发
- DMA1 自动搬运 ADC 转换结果到内存缓冲区，DMA 完成中断触发 PID
- ADC 时钟 = PCLK2/8 = 12MHz，12 位，采样时间 7.5 周期

- [ ] **Step 1: motor.h 添加 ADC/DMA 接口**

```c
void Motor_InitAdc(void);
void Motor_StartAdcConversion(void);
extern volatile uint16_t motor_adc_dma_buf_[MOTOR_COUNT];
extern volatile bool motor_adc_ready_;
```

- [ ] **Step 2: motor.c 实现 ADC + DMA 初始化**

```c
#include "ch32v20x_dma.h"

/* DMA 缓冲区：ADC 自动写入 */
__attribute__((aligned(4)))
volatile uint16_t motor_adc_dma_buf_[MOTOR_COUNT];
volatile bool motor_adc_ready_;

void Motor_InitAdc(void)
{
    ADC_InitTypeDef adc;
    GPIO_InitTypeDef gpio;
    DMA_InitTypeDef dma;

    RCC_APB2PeriphClockCmd(RCC_APB2Periph_ADC1 | RCC_APB2Periph_GPIOA, ENABLE);
    RCC_AHBPeriphClockCmd(RCC_AHBPeriph_DMA1, ENABLE);

    /* PA0~PA7 模拟输入 */
    gpio.GPIO_Pin = GPIO_Pin_0 | GPIO_Pin_1 | GPIO_Pin_2 | GPIO_Pin_3
                  | GPIO_Pin_4 | GPIO_Pin_5 | GPIO_Pin_6 | GPIO_Pin_7;
    gpio.GPIO_Mode = GPIO_Mode_AIN;
    GPIO_Init(GPIOA, &gpio);

    /* === DMA1 通道 1: ADC1 → motor_adc_dma_buf_ === */
    DMA_DeInit(DMA1_Channel1);
    dma.DMA_PeripheralBaseAddr = (uint32_t)&ADC1->RDATAR;
    dma.DMA_MemoryBaseAddr = (uint32_t)motor_adc_dma_buf_;
    dma.DMA_DIR = DMA_DIR_PeripheralSRC;
    dma.DMA_BufferSize = MOTOR_COUNT;
    dma.DMA_PeripheralInc = DMA_PeripheralInc_Disable;
    dma.DMA_MemoryInc = DMA_MemoryInc_Enable;
    dma.DMA_PeripheralDataSize = DMA_PeripheralDataSize_HalfWord;
    dma.DMA_MemoryDataSize = DMA_MemoryDataSize_HalfWord;
    dma.DMA_Mode = DMA_Mode_Normal;
    dma.DMA_Priority = DMA_Priority_High;
    dma.DMA_M2M = DMA_M2M_Disable;
    DMA_Init(DMA1_Channel1, &dma);

    /* DMA 完成中断 */
    DMA_ITConfig(DMA1_Channel1, DMA_IT_TC, ENABLE);

    /* === ADC1 配置 === */
    ADC_DeInit(ADC1);
    RCC_ADCCLKConfig(RCC_PCLK2_Div8);  /* ADC 时钟 = 12MHz */

    adc.ADC_Mode = ADC_Mode_Independent;
    adc.ADC_ScanConvMode = ENABLE;
    adc.ADC_ContinuousConvMode = DISABLE;
    adc.ADC_ExternalTrigConv = ADC_ExternalTrigConv_None;
    adc.ADC_DataAlign = ADC_DataAlign_Right;
    adc.ADC_NbrOfChannel = MOTOR_COUNT;
    ADC_Init(ADC1, &adc);

    /* 配置通道顺序：采样时间 7.5 周期 */
    ADC_RegularChannelConfig(ADC1, ADC_Channel_0, 1, ADC_SampleTime_7Cycles5);
    ADC_RegularChannelConfig(ADC1, ADC_Channel_1, 2, ADC_SampleTime_7Cycles5);
    ADC_RegularChannelConfig(ADC1, ADC_Channel_2, 3, ADC_SampleTime_7Cycles5);
    ADC_RegularChannelConfig(ADC1, ADC_Channel_3, 4, ADC_SampleTime_7Cycles5);
    ADC_RegularChannelConfig(ADC1, ADC_Channel_4, 5, ADC_SampleTime_7Cycles5);
    ADC_RegularChannelConfig(ADC1, ADC_Channel_5, 6, ADC_SampleTime_7Cycles5);
    ADC_RegularChannelConfig(ADC1, ADC_Channel_6, 7, ADC_SampleTime_7Cycles5);
    ADC_RegularChannelConfig(ADC1, ADC_Channel_7, 8, ADC_SampleTime_7Cycles5);

    /* 使能 ADC + 校准 */
    ADC_Cmd(ADC1, ENABLE);
    ADC_ResetCalibration(ADC1);
    while (ADC_GetResetCalibrationStatus(ADC1));
    ADC_StartCalibration(ADC1);
    while (ADC_GetCalibrationStatus(ADC1));
}
```

- [ ] **Step 3: 实现 ADC 软件触发和 DMA 中断**

```c
void Motor_StartAdcConversion(void)
{
    motor_adc_ready_ = false;
    DMA_Cmd(DMA1_Channel1, DISABLE);
    DMA1_Channel1->CNTR = MOTOR_COUNT;          /* 重置 DMA 计数器 */
    DMA_Cmd(DMA1_Channel1, ENABLE);
    ADC_SoftwareStartConvCmd(ADC1, ENABLE);
}

/* DMA1 通道 1 完成中断 → ADC 数据就绪 */
void DMA1_Channel1_IRQHandler(void) __attribute__((interrupt("WCH-Interrupt-fast")));
void DMA1_Channel1_IRQHandler(void)
{
    if (DMA_GetITStatus(DMA1_Channel1, DMA_IT_TC)) {
        DMA_ClearITPendingBit(DMA1_Channel1, DMA_IT_TC);
        motor_adc_ready_ = true;
        Motor_RunControlLoop();
    }
}
```

---

### Task 3: PID 控制器

**Files:**
- Create: `User/pid.h`
- Create: `User/pid.c`

- [ ] **Step 1: pid.h 声明**

```c
#pragma once
#include <stdint.h>

typedef struct {
    float kp;
    float ki;
    float kd;
    float integral;
    float prev_error;
    float output_min;
    float output_max;
    float integral_limit;
} PidCtx;

void Pid_Init(PidCtx *pid, float kp, float ki, float kd);
float Pid_Update(PidCtx *pid, float setpoint, float feedback);
void Pid_Reset(PidCtx *pid);
```

- [ ] **Step 2: pid.c 实现**

```c
#include "pid.h"

void Pid_Init(PidCtx *pid, float kp, float ki, float kd)
{
    pid->kp = kp;
    pid->ki = ki;
    pid->kd = kd;
    pid->integral = 0;
    pid->prev_error = 0;
    pid->output_min = -999.0f;
    pid->output_max = 999.0f;
    pid->integral_limit = 500.0f;
}

float Pid_Update(PidCtx *pid, float setpoint, float feedback)
{
    float error = setpoint - feedback;
    float p_term = pid->kp * error;

    pid->integral += error;
    if (pid->integral > pid->integral_limit)
        pid->integral = pid->integral_limit;
    else if (pid->integral < -pid->integral_limit)
        pid->integral = -pid->integral_limit;
    float i_term = pid->ki * pid->integral;

    float d_term = pid->kd * (error - pid->prev_error);
    pid->prev_error = error;

    float output = p_term + i_term + d_term;
    if (output > pid->output_max) output = pid->output_max;
    else if (output < pid->output_min) output = pid->output_min;

    return output;
}

void Pid_Reset(PidCtx *pid)
{
    pid->integral = 0;
    pid->prev_error = 0;
}
```

---

### Task 4: 控制循环集成

**Files:**
- Modify: `User/motor.h` (添加控制循环接口)
- Modify: `User/motor.c` (添加控制循环实现)

- [ ] **Step 1: motor.h 添加控制循环接口**

```c
void Motor_InitControl(void);
void Motor_RunControlLoop(void);  /* 从 ADC ISR 调用 */
void Motor_SetTarget(uint8_t ch, uint16_t target_adc);
void Motor_StopAll(void);

/* 电机状态 */
typedef struct {
    uint16_t target_adc;       /* 目标位置 (0~4095) */
    uint16_t current_adc;      /* 当前位置 (0~4095) */
    MotorDir dir;
    uint16_t duty;
    PidCtx pid;
} MotorState;

extern MotorState motor_states_[MOTOR_COUNT];
```

- [ ] **Step 2: motor.c 实现 Motor_InitControl 和 Motor_RunControlLoop**

```c
MotorState motor_states_[MOTOR_COUNT];
static bool motor_stall_flag_[MOTOR_COUNT];
static uint16_t motor_stall_count_[MOTOR_COUNT];

void Motor_InitControl(void)
{
    for (int i = 0; i < MOTOR_COUNT; i++) {
        motor_states_[i].target_adc = 2048;  /* 中间位置 */
        motor_states_[i].current_adc = 2048;
        motor_states_[i].dir = kMotorDir_Stop;
        motor_states_[i].duty = 0;
        Pid_Init(&motor_states_[i].pid, 0.5f, 0.01f, 0.1f);
        motor_stall_flag_[i] = false;
        motor_stall_count_[i] = 0;
    }
}

void Motor_RunControlLoop(void)
{
    if (!motor_adc_ready_) return;

    for (int i = 0; i < MOTOR_COUNT; i++) {
        motor_states_[i].current_adc = motor_adc_values_[i];

        if (i == MOTOR_3) {
            /* 电机 3 GPIO 开关控制 */
            if (motor_states_[i].target_adc > motor_states_[i].current_adc + 20) {
                Motor_SetPwm(i, kMotorDir_Forward, 500);
            } else if (motor_states_[i].target_adc < motor_states_[i].current_adc - 20) {
                Motor_SetPwm(i, kMotorDir_Reverse, 500);
            } else {
                Motor_SetPwm(i, kMotorDir_Stop, 0);
            }
            continue;
        }

        float output = Pid_Update(&motor_states_[i].pid,
                                  (float)motor_states_[i].target_adc,
                                  (float)motor_states_[i].current_adc);

        if (output > 0) {
            motor_states_[i].dir = kMotorDir_Forward;
            motor_states_[i].duty = (uint16_t)(output > 999.0f ? 999 : (uint16_t)output);
        } else if (output < 0) {
            motor_states_[i].dir = kMotorDir_Reverse;
            motor_states_[i].duty = (uint16_t)(-output > 999.0f ? 999 : (uint16_t)(-output));
        } else {
            motor_states_[i].dir = kMotorDir_Stop;
            motor_states_[i].duty = 0;
        }

        Motor_SetPwm(i, motor_states_[i].dir, motor_states_[i].duty);
    }
}
```

---

### Task 5: USB HID1 电机控制接口

**Files:**
- Modify: `User/usb/usb_desc.cpp`
- Modify: `User/usb/usb_impl.h`
- Modify: `User/usb/usb_impl.c`

- [ ] **Step 1: usb_desc.cpp 添加 HID1 接口描述符**

在现有 `kConfig` 中添加第二个 HID 接口：
```cpp
static constexpr auto kConfig =
tpusb::Config{
    tpusb::ConfigInitPack{ ... },
    tpusb::hid::HID_Interface{   /* HID0: printf */
        ...
    },
    tpusb::hid::HID_Interface{   /* HID1: motor control */
        tpusb::InterfaceInitPackClassed{
            .interface_no = 1,
            .alter = 0,
            .protocol = 0,
            .str_id = 0,
        },
        tpusb::hid::HID_Descriptor<1>{
            tpusb::hid::HID_Descriptor_InitPack{
                .bcd_hid = 0x0111,
                .country_code = 0,
            },
            std::array{
                tpusb::hid::HID_DescriptorLengthDesc{
                    .type = 0x22,
                    .length = sizeof(kMotorHidReportDesc)
                }
            }
        },
        tpusb::Endpoint{
            tpusb::InterruptInitPack{
                .address = 0x82,         /* EP2 IN */
                .max_pack_size = 64,
                .interval = 1,
            }
        },
        tpusb::Endpoint{
            tpusb::InterruptInitPack{
                .address = 0x02,         /* EP2 OUT */
                .max_pack_size = 64,
                .interval = 1,
            }
        },
    }
};
```

添加 HID1 报告描述符：
```cpp
/* HID1 Report Descriptor: motor control commands + status */
static constexpr uint8_t kMotorHidReportDesc[] = {
    0x06, 0x01, 0xFF,       /* Usage Page (Vendor 0xFF01) */
    0x09, 0x01,             /* Usage (Motor Control) */
    0xA1, 0x01,             /* Collection (Application) */
    0x09, 0x02,             /*   Usage (Commands) */
    0x15, 0x00,             /*   Logical Min (0) */
    0x26, 0xFF, 0x00,       /*   Logical Max (255) */
    0x75, 0x08,             /*   Report Size (8) */
    0x95, 64,               /*   Report Count (64) */
    0x91, 0x02,             /*   Output (Data,Var,Abs) */
    0x09, 0x03,             /*   Usage (Status) */
    0x15, 0x00,
    0x26, 0xFF, 0x00,
    0x75, 0x08,
    0x95, 64,
    0x81, 0x02,             /*   Input (Data,Var,Abs) */
    0xC0,
};
```

更新 `UsbDesc_Hid` 以支持接口索引：
```cpp
uint8_t const* UsbDesc_Hid(uint16_t interface_idx, uint16_t* len)
{
    if (interface_idx == 0) {
        *len = sizeof(kHidReportDesc);
        return kHidReportDesc;
    } else if (interface_idx == 1) {
        *len = sizeof(kMotorHidReportDesc);
        return kMotorHidReportDesc;
    }
    *len = 0;
    return nullptr;
}
```

- [ ] **Step 2: usb_impl.h 添加 HID1 端点和 API**

```c
#define HID1_IN_EP_ADDRESS   0x82
#define HID1_OUT_EP_ADDRESS  0x02
#define HID1_EP_MPSIZE       64

void HID1_Init(void);
bool HID1_Read(uint8_t* buf, uint32_t* len);
bool HID1_Write(const uint8_t* buf, uint32_t len);
void HID1_ProcessCommand(void);
```

- [ ] **Step 3: usb_impl.c 实现 HID1 端点初始化**

```c
void UsbImpl_InitAndOpenEndpoints()
{
    /* 现有 EP1 TX (HID0 printf) */
    USBFSD->UEP4_1_MOD = USBFS_UEP1_TX_EN | USBFS_UEP1_RX_EN;
    /* 需要配置 EP2 (HID1) 通过 UEP2_3_MOD */
    USBFSD->UEP2_3_MOD = USBFS_UEP2_TX_EN | USBFS_UEP2_RX_EN;

    USBFSD->UEP1_DMA = (uint32_t)hid_report_buf;
    USBFSD->UEP1_TX_LEN = 0;
    USBFSD->UEP1_TX_CTRL = USBFS_UEP_T_RES_NAK;

    USBFSD->UEP2_DMA = (uint32_t)hid1_report_buf;
    USBFSD->UEP2_TX_LEN = 0;
    USBFSD->UEP2_TX_CTRL = USBFS_UEP_T_RES_NAK;
    USBFSD->UEP2_RX_CTRL = USBFS_UEP_R_RES_ACK;

    hid_tx_busy = false;
}
```

- [ ] **Step 4: HID1 OUT 接收中断处理**

```c
void UsbImpl_EpOutComplete(uint8_t ep_num, uint16_t count)
{
    if (ep_num == 2) {
        /* HID1 OUT: 接收上位机命令 */
        memcpy(hid1_rx_buf, hid1_report_buf, count);
        hid1_rx_len = count;
        hid1_rx_pending = true;
        /* 切换 DMA 缓冲区（如果需要双缓冲）或重新使能 RX */
        USBFSD->UEP2_RX_CTRL = (USBFSD->UEP2_RX_CTRL & ~USBFS_UEP_R_RES_MASK)
                              | USBFS_UEP_R_RES_ACK;
    }
}
```

- [ ] **Step 5: HID1 IN 发送处理**

```c
void UsbImpl_EpInComplete(uint8_t ep_num)
{
    switch ((enum UsbEndpointNumber)ep_num) {
        case kUsbEndpoint_HidIn:
            _HidInHandler();
            break;
        case kUsbEndpoint_Hid1In:
            /* HID1 IN complete — status sent, mark ready */
            hid1_tx_busy = false;
            USBFSD->UEP2_TX_CTRL ^= USBFS_UEP_T_TOG;
            break;
    }
}
```

- [ ] **Step 6: 添加命令解析函数**

```c
/* HID1 命令格式：64 字节报告 */
/* byte 0: 命令 ID */
/*   0x01: 设置目标位置 (bytes 1-16: 8路目标值 × 2字节) */
/*   0x02: 读取状态 */
/*   0x03: 停止所有电机 */
/*   0x04: 设置 PID 参数 */

void HID1_ProcessCommand(void)
{
    if (!hid1_rx_pending) return;
    hid1_rx_pending = false;

    switch (hid1_rx_buf[0]) {
        case 0x01: /* 设置目标位置 */
            for (int i = 0; i < MOTOR_COUNT; i++) {
                uint16_t target = (uint16_t)hid1_rx_buf[1 + i*2]
                                | ((uint16_t)hid1_rx_buf[2 + i*2] << 8);
                Motor_SetTarget(i, target);
            }
            break;
        case 0x02: /* 读取状态 — 填充 IN 报告 */
            _Hid1BuildStatusReport();
            break;
        case 0x03: /* 停止所有 */
            Motor_StopAll();
            break;
    }
}
```

---

### Task 6: SysTick 集成

**Files:**
- Modify: `User/ch32v20x_it.c`

- [ ] **Step 1: SysTick_Handler 添加 ADC 触发**

```c
void SysTick_Handler(void)
{
    Tick_Increment();
    Motor_StartAdcConversion();    /* 触发 ADC (DMA 自动搬运) */
    HID_Flush();                  /* 继续轮询 HID0 printf */
}
```

- [ ] **Step 2: Startup 文件检查 DMA1 中断向量**

确保 `startup_ch32v20x_D6.S` 中有 `DMA1_Channel1_IRQHandler` 的向量入口（通常在 DMA1_Channel1_IRQn = 27 位置）。如果使用了 weak 定义，在 `ch32v20x_it.c` 中定义即可。

---

### Task 7: CMakeLists 与 main.c 更新

**Files:**
- Modify: `CMakeLists.txt`
- Modify: `User/main.c`

- [ ] **Step 1: CMakeLists.txt 添加新源文件**

```cmake
set(SRC_FILES 
    ...
    "${CMAKE_CURRENT_SOURCE_DIR}/User/motor.c"
    "${CMAKE_CURRENT_SOURCE_DIR}/User/pid.c"
)
```

- [ ] **Step 2: main.c 初始化所有模块**

```c
int main(void)
{
    NVIC_PriorityGroupConfig(NVIC_PriorityGroup_1);
    SystemCoreClockUpdate();
    Tick_Init();

    printf("SystemClk:%d\r\n", SystemCoreClock);

    Motor_InitPwm();
    Motor_InitAdc();
    Motor_InitControl();

    HID_Init();
    Usbd_Init();
    Usbd_Connect();
    printf("USB HID ready\r\n");

    while (1) {
        __asm__ volatile("wfi");
        HID1_ProcessCommand();
    }
}
```

---

## 未解决问题

1. PID 参数（kp, ki, kd）需要实际测试调整，初始值可能需要根据不同电机的机械特性单独设置
2. DMA1 通道 1 中断优先级需要确定相对于 SysTick 和 USBFS 的高低

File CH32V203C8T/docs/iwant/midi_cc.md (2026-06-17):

# 需求文档：八路马达线性电位器 MCU 固件 — USB MIDI CC 双向联动

## 背景与范围

现有固件已通过 USB HID 实现八路马达线性电位器的位置读取与设置。本需求在**不改动现有 HID 功能**的前提下，扩展为 USB 复合设备，新增 USB MIDI 类接口，实现电位器位置与 MIDI CC 消息的双向联动。

- **MCU**：CH32V 系列
- **USB 拓扑**：单一 USB 复合设备（Composite Device），同时枚举 HID 接口 + MIDI 接口
- **USB MIDI 实现**：使用tpusb生成 USB 描述符

---

## 1. USB 描述符扩展

### 1.1 复合设备结构

在现有 HID 接口描述符之后，追加以下接口：

```
Configuration Descriptor
├── Interface 0：现有 HID 接口（保持不变）
├── Interface 1：Audio Control（USB MIDI 规范要求的空 AC 接口）
└── Interface 2：MIDIStreaming（实际收发 MIDI 数据的接口）
    ├── Endpoint IN  (Bulk) — MCU → Host，发送 MIDI 事件包
    └── Endpoint OUT (Bulk) — Host → MCU，接收 MIDI 事件包
```

### 1.2 描述符要求

| 字段 | 值 |
|---|---|
| bDeviceClass | 0x00（由接口决定） |
| 设备级 IAD | 为 Audio/MIDI 接口对添加 Interface Association Descriptor |
| MIDI IN Jack | 1 个 Embedded Jack（jackId = 1） |
| MIDI OUT Jack | 1 个 Embedded Jack（jackId = 1），关联到 Bulk IN 端点 |
| Bulk 端点包大小 | 64 字节 |

### 1.3 兼容性约束

- `bcdUSB` 设为 `0x0200`（USB 2.0）
- 端点地址不得与现有 HID 端点冲突，编译期静态分配
- Windows 下无需额外驱动（Class-compliant USB MIDI 1.0）

---

## 2. MIDI 数据格式

所有 MIDI 数据通过 **USB MIDI Event Packet**（4 字节/包）传输，格式如下：

```
Byte 0: Cable Number (高4位) | Code Index Number (低4位)
Byte 1: MIDI Status Byte  (e.g. 0xB0 | channel)
Byte 2: MIDI Data Byte 1  (CC 编号)
Byte 3: MIDI Data Byte 2  (CC 值)
```

本项目仅处理 **Control Change（CC）** 消息，CIN = `0x0B`。

---

## 3. TX 方向：电位器 → MIDI CC 发送

### 3.1 触发条件

- 在现有位置轮询循环中，检测每路电位器的位置变化。
- 仅当某路的映射位置值（CC 值）与上次发送值**不同**时，才构造并发送 CC 包。

### 3.2 数值映射

```c
// 电位器原始值已归一化为 [0, 4095]（12-bit ADC）或 [0, 255]，以实际为准
// 映射到 MIDI CC [0, 127]
uint8_t cc_value = (uint8_t)(fader_raw * 127 / FADER_MAX);
```

### 3.3 发送行为

- 每路电位器各维护一个 `last_sent_cc[8]` 数组，用于去抖/去重。
- 位置变化超过最小阈值（建议 1 个 CC 步进单位）才触发发送，避免抖动造成消息洪泛。
- 多路同时变化时，在同一 USB 传输批次中依次打包发送。

---

## 4. RX 方向：MIDI CC → 电位器驱动

### 4.1 接收处理

- 在 USB OUT 端点中断或轮询回调中解析收到的 MIDI Event Packet。
- 仅处理 CC 消息（`Status & 0xF0 == 0xB0`），其余消息类型静默忽略。

### 4.2 路由与映射

- 根据收到的 `(MIDI 通道, CC 编号)` 查找映射表，定位目标电位器编号。
- 将 CC 值 `[0, 127]` 反向映射为电位器目标位置值：

```c
uint16_t target_pos = (uint16_t)(cc_value * FADER_MAX / 127);
```

- 调用**现有**的电位器位置设置接口驱动对应马达。

### 4.3 未匹配消息

- 未在映射表中命中的 CC 消息直接丢弃，不产生任何副作用。

---

## 5. 防回环

当 MCU 正在响应 RX 命令驱动某路电位器时，该路电位器的位置变化**不得**触发 TX 发送，避免 MIDI 消息回环。

### 实现方式

```c
// 每路维护一个标志位
volatile bool fader_rx_active[8] = {false};

// RX 驱动开始时置位
fader_rx_active[i] = true;
set_fader_position(i, target_pos);

// TX 检测时跳过被标记的通道
if (!fader_rx_active[i] && cc_value != last_sent_cc[i]) {
    send_midi_cc(i, cc_value);
}

// 电位器到达目标（或超时后）清除标志
fader_rx_active[i] = false;
```

超时保护建议：若马达在 **500 ms** 内未到达目标位置，强制清除标志，防止通道永久静默。

---

## 6. CC 映射配置

默认映射表（硬编码为 `const` 数组，可后续扩展为可配置）：

| 电位器编号 | MIDI 通道 | CC 编号 |
|:---:|:---:|:---:|
| 0 | 1 | 0 |
| 1 | 1 | 1 |
| 2 | 1 | 2 |
| 3 | 1 | 3 |
| 4 | 1 | 4 |
| 5 | 1 | 5 |
| 6 | 1 | 6 |
| 7 | 1 | 7 |

---

## 7. 现有功能约束（不得改动）

| 约束 | 说明 |
|---|---|
| HID 描述符 | 不得修改现有 HID Report Descriptor 及端点配置 |
| HID 轮询行为 | 现有 HID 位置上报逻辑保持不变 |
| 位置读取接口 | `read_fader_position(uint8_t index)` 保持原签名 |
| 位置设置接口 | `set_fader_position(uint8_t index, uint16_t pos)` 保持原签名 |

---

## 8. 非功能需求

| 编号 | 描述 |
|---|---|
| NF1 | 电位器变化到 MIDI CC 发出，端到端延迟 < 10 ms |
| NF2 | MIDI 接口不得影响 HID 接口的轮询周期与响应时间 |
| NF3 | USB 枚举成功后，HID 与 MIDI 接口均应在 Windows 设备管理器中正常识别，无需安装驱动 |
| NF4 | 固件中不引入动态内存分配（`malloc`/`free`），所有缓冲区静态分配 |

---

## 9. 验收标准

1. **枚举验证**：设备插入 Windows PC 后，设备管理器同时出现 HID 设备与"USB 音频设备 / MIDI"条目。
2. **TX 验证**：手动推动任意电位器，MIDI 监视器（如 MIDI-OX）收到对应 CC 消息，值随位置线性变化。
3. **RX 验证**：通过 MIDI 工具向设备发送 CC 消息，对应电位器自动移动到目标位置。
4. **防回环验证**：RX 驱动电位器移动期间，MIDI 监视器中不出现该路的 TX CC 消息。
5. **HID 兼容性验证**：MIDI 功能开启后，原有 HID 读写功能行为不变。

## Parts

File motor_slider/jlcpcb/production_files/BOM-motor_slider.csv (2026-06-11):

Comment | Designator | Footprint | LCSC | Quantity
CH32V203C8T6 | U3 | LQFP-48_L7.0-W7.0-P0.50-LS9.0-BL | C3001172 | 1
MOTOR1 | U2 | CONN-SMD_2P-P1.00_MEGASTAR_ZX-SH1.0-2PLT | C7430451 | 1
MOTOR2 | U5 | CONN-SMD_2P-P1.00_MEGASTAR_ZX-SH1.0-2PLT | C7430451 | 1
MOTOR3 | U6 | CONN-SMD_2P-P1.00_MEGASTAR_ZX-SH1.0-2PLT | C7430451 | 1
MOTOR4 | U7 | CONN-SMD_2P-P1.00_MEGASTAR_ZX-SH1.0-2PLT | C7430451 | 1
MOTOR5 | U9 | CONN-SMD_2P-P1.00_MEGASTAR_ZX-SH1.0-2PLT | C7430451 | 1
MOTOR6 | U10 | CONN-SMD_2P-P1.00_MEGASTAR_ZX-SH1.0-2PLT | C7430451 | 1
MOTOR7 | U12 | CONN-SMD_2P-P1.00_MEGASTAR_ZX-SH1.0-2PLT | C7430451 | 1
MOTOR8 | U13 | CONN-SMD_2P-P1.00_MEGASTAR_ZX-SH1.0-2PLT | C7430451 | 1
POT1 | U14 | CONN-SMD_3P-P1.00_HDGC_HDGC1002WV-S-3P | C7430452 | 1
POT2 | U17 | CONN-SMD_3P-P1.00_HDGC_HDGC1002WV-S-3P | C7430452 | 1
POT3 | U18 | CONN-SMD_3P-P1.00_HDGC_HDGC1002WV-S-3P | C7430452 | 1
POT4 | U19 | CONN-SMD_3P-P1.00_HDGC_HDGC1002WV-S-3P | C7430452 | 1
POT5 | U20 | CONN-SMD_3P-P1.00_HDGC_HDGC1002WV-S-3P | C7430452 | 1
POT6 | U21 | CONN-SMD_3P-P1.00_HDGC_HDGC1002WV-S-3P | C7430452 | 1
POT7 | U23 | CONN-SMD_3P-P1.00_HDGC_HDGC1002WV-S-3P | C7430452 | 1
POT8 | U24 | CONN-SMD_3P-P1.00_HDGC_HDGC1002WV-S-3P | C7430452 | 1
SWD | U22 | CONN-SMD_3P-P1.00_HDGC_HDGC1002WV-S-3P | C7430452 | 1
100nF | C26 | C0603 |  | 1
100nF | C21 | C0603 |  | 1
1k | R18 | R0603 |  | 1
1k | R24 | R0603 |  | 1
1k | R20 | R0603 |  | 1
1k | R23 | R0603 |  | 1
1k | R21 | R0603 |  | 1
1k | R22 | R0603 |  | 1
1k | R17 | R0603 |  | 1
1k | R19 | R0603 |  | 1
100nF | C29 | C0603 |  | 1
100nF | C30 | C0603 |  | 1
100nF | C24 | C0603 |  | 1
DRV8833PWP | U1 | HTSSOP-16-1EP_4.4x5mm_P0.65mm_EP3.4x5mm_Mask2.46x2.31mm_ThermalVias |  | 1
10uF | C9 | C_0805_2012Metric |  | 1
10uF | C6 | C_0805_2012Metric |  | 1
5.1k | R14 | R0603 |  | 1
5.1k | R3 | R0603 |  | 1
5.1k | R11 | R0603 |  | 1
5.1k | R2 | R0603 |  | 1
10uF | C14 | C_0805_2012Metric |  | 1
DRV8833PWP | U15 | HTSSOP-16-1EP_4.4x5mm_P0.65mm_EP3.4x5mm_Mask2.46x2.31mm_ThermalVias |  | 1
VM | J6 | PinSocket_1x01_P2.54mm_Vertical |  | 1
0.1R | R12 | R0603 |  | 1
10nF | C15 | C0603 |  | 1
BOOT | SW1 | 小龟轻触开关3_4_22.0MM |  | 1
10uF | C17 | C_0805_2012Metric |  | 1
2.2uF | C5 | C_0805_2012Metric |  | 1
10uF | C20 | C_0805_2012Metric |  | 1
GND | J7 | PinSocket_1x01_P2.54mm_Vertical |  | 1
0.1R | R10 | R0603 |  | 1
100nF | C25 | C0603 |  | 1
10nF | C7 | C0603 |  | 1
0.1R | R13 | R0603 |  | 1
5.1k | R7 | R0603 |  | 1
20pF | C2 | C0603 |  | 1
ME6210A33M3G | U4 | SOT-23 |  | 1
ME6210A33M3G | U16 | SOT-23 |  | 1
20pF | C3 | C0603 |  | 1
10k | R1 | R0603 |  | 1
100nF | C27 | C0603 |  | 1
0.1R | R5 | R0603 |  | 1
DRV8833PWP | U11 | HTSSOP-16-1EP_4.4x5mm_P0.65mm_EP3.4x5mm_Mask2.46x2.31mm_ThermalVias |  | 1
10nF | C12 | C0603 |  | 1
0.1R | R6 | R0603 |  | 1
2.2uF | C10 | C_0805_2012Metric |  | 1
10uF | C8 | C_0805_2012Metric |  | 1
Conn_02x02_Odd_Even | J2 | PinSocket_2x02_P2.54mm_Vertical |  | 1
0.1R | R9 | R0603 |  | 1
100nF | C4 | C0603 |  | 1
USB_C_Receptacle_USB2.0_16P | J1 | USB_C_Receptacle_G-Switch_GT-USB-7010ASV |  | 1
DRV8833PWP | U8 | HTSSOP-16-1EP_4.4x5mm_P0.65mm_EP3.4x5mm_Mask2.46x2.31mm_ThermalVias |  | 1
10uF | C11 | C_0805_2012Metric |  | 1
10uF | C19 | C_0805_2012Metric |  | 1
Conn_01x03 | J8 | PinSocket_1x03_P2.54mm_Vertical |  | 1
0.1R | R16 | R0603 |  | 1
2.2uF | C13 | C_0805_2012Metric |  | 1
10nF | C18 | C0603 |  | 1
100nF | C28 | C0603 |  | 1
100nF | C33 | C0603 |  | 1
100nF | C32 | C0603 |  | 1
100nF | C1 | C0603 |  | 1
100nF | C31 | C0603 |  | 1
2.2uF | C16 | C_0805_2012Metric |  | 1
RESET | SW2 | 小龟轻触开关3_4_22.0MM |  | 1
1M | R4 | R0603 |  | 1
0.1R | R15 | R0603 |  | 1
8M | Y1 | Crystal_SMD_3225-4Pin_3.2x2.5mm |  | 1
5.1k | R8 | R0603 |  | 1
10uF | C22 | C_0805_2012Metric |  | 1
100nF | C23 | C0603 |  | 1
3.3R | L1 | L_0603_1608Metric |  | 1

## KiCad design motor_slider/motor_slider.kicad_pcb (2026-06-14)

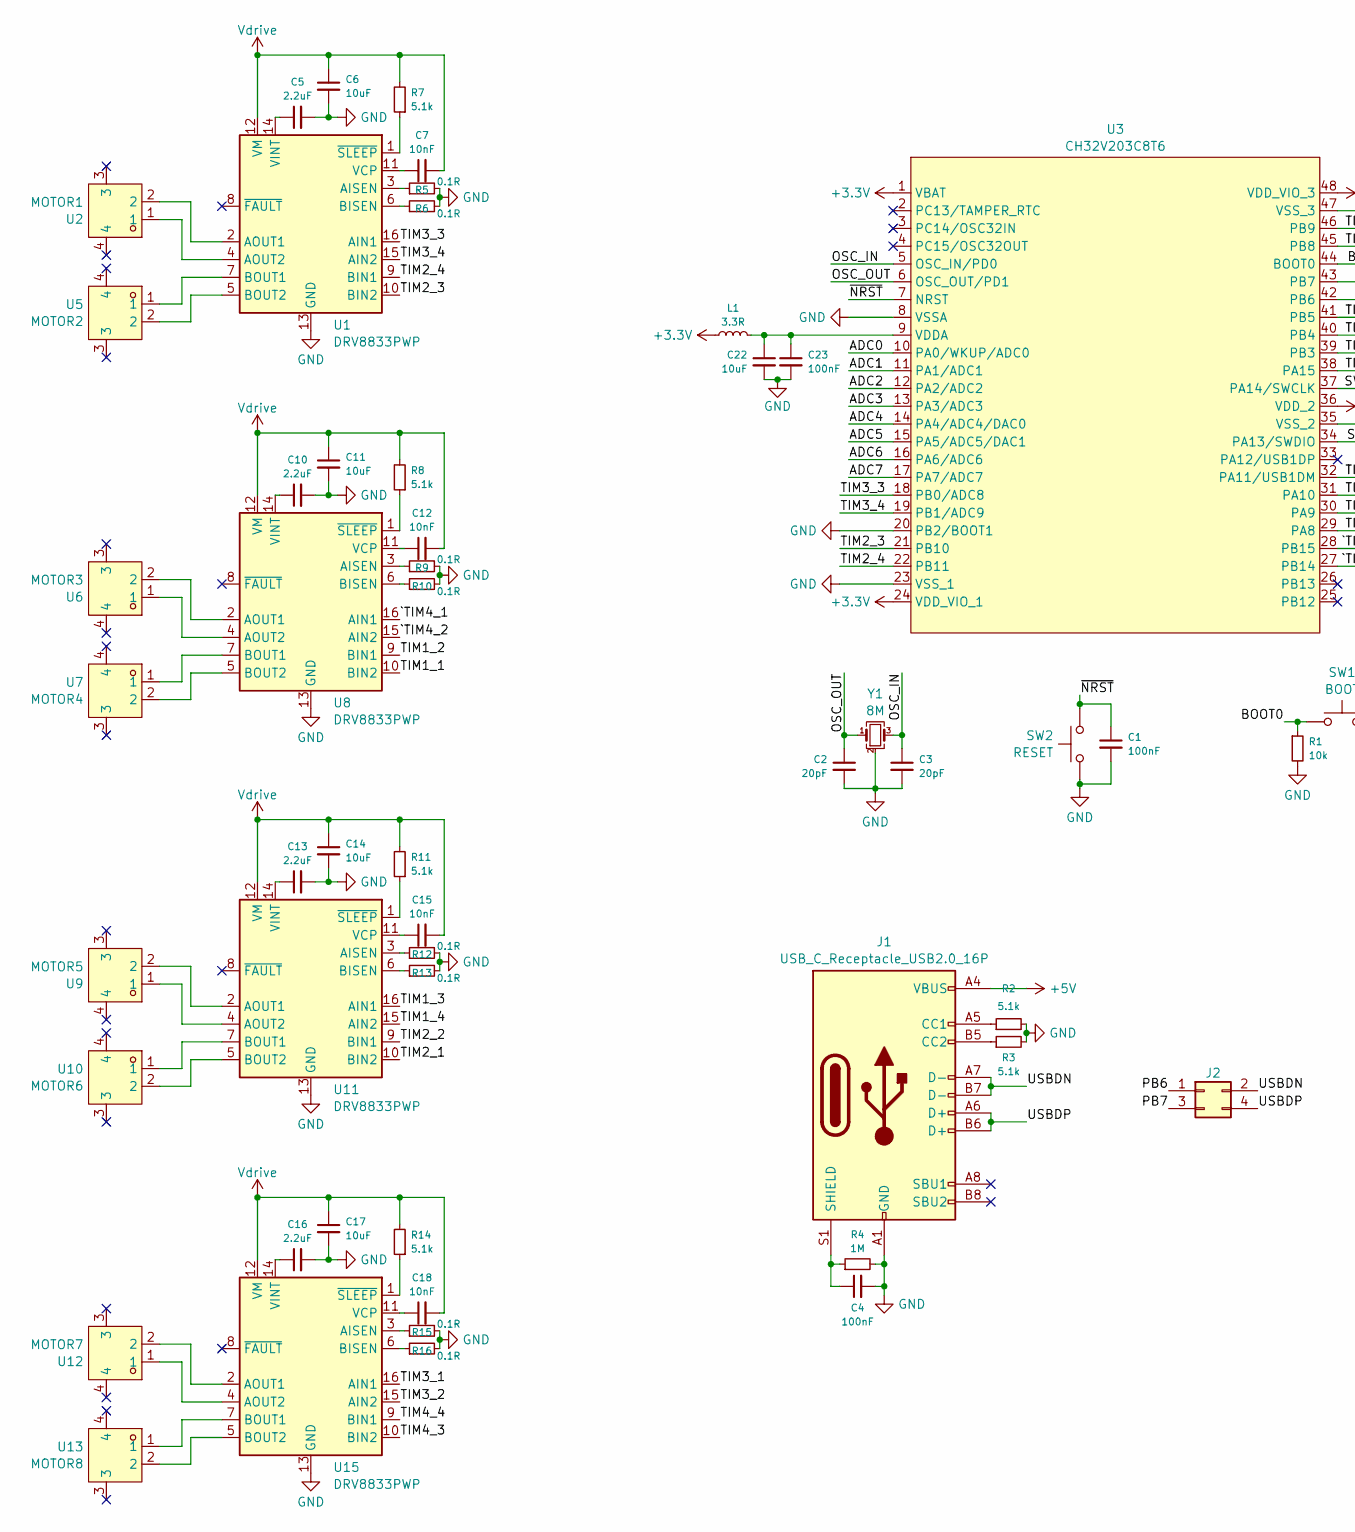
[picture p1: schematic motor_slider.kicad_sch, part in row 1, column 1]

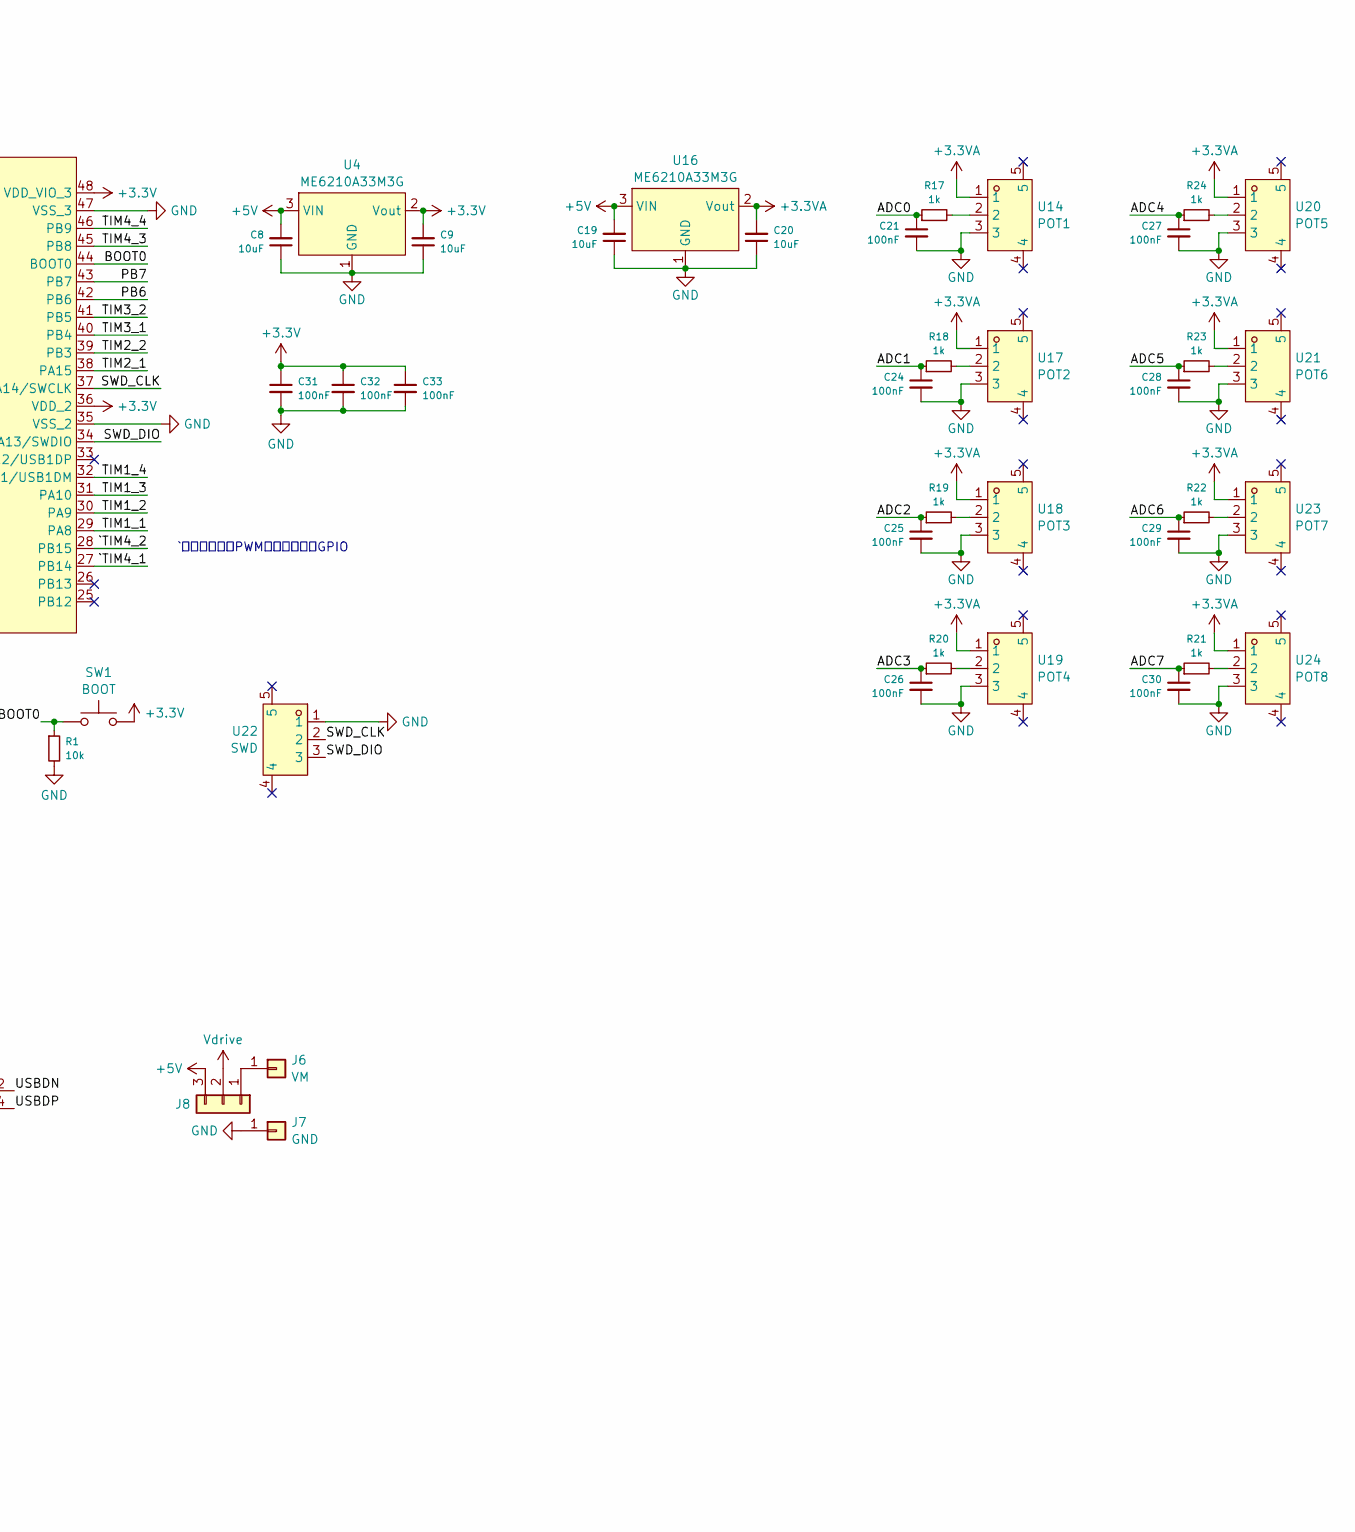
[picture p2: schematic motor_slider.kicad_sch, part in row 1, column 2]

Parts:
C1, C4, C21, C23, C24, C25, C26, C27, C28, C29, C30, C31, C32, C33: 100nF; C0603
C2, C3: 20pF; C0603
C5, C10, C13, C16: 2.2uF; C_0805_2012Metric
C6, C8, C9, C11, C14, C17, C19, C20, C22: 10uF; C_0805_2012Metric
C7, C12, C15, C18: 10nF; C0603
J1: USB_C_Receptacle_USB2.0_16P; USB_C_Receptacle_G-Switch_GT-USB-7010ASV
J2: Conn_02x02_Odd_Even; PinSocket_2x02_P2.54mm_Vertical
J6: VM; PinSocket_1x01_P2.54mm_Vertical
J7: GND; PinSocket_1x01_P2.54mm_Vertical
J8: Conn_01x03; PinSocket_1x03_P2.54mm_Vertical
L1: 3.3R; L_0603_1608Metric
R1: 10k; R0603
R2, R3, R7, R8, R11, R14: 5.1k; R0603
R4: 1M; R0603
R5, R6, R9, R10, R12, R13, R15, R16: 0.1R; R0603
R17, R18, R19, R20, R21, R22, R23, R24: 1k; R0603
SW1: BOOT; 小龟轻触开关3_4_22.0MM
SW2: RESET; 小龟轻触开关3_4_22.0MM
U1, U8, U11, U15: DRV8833PWP; HTSSOP-16-1EP_4.4x5mm_P0.65mm_EP3.4x5mm_Mask2.46x2.31mm_The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
U2: MOTOR1; CONN-SMD_2P-P1.00_MEGASTAR_ZX-SH1.0-2PLT; MPN ZX-SH1.0-2PLT; LCSC Part C7430451
U3: CH32V203C8T6; LQFP-48_L7.0-W7.0-P0.50-LS9.0-BL; MPN CH32V203C8T6; LCSC Part C3001172
U4, U16: ME6210A33M3G; SOT-23
U5: MOTOR2; CONN-SMD_2P-P1.00_MEGASTAR_ZX-SH1.0-2PLT; MPN ZX-SH1.0-2PLT; LCSC Part C7430451
U6: MOTOR3; CONN-SMD_2P-P1.00_MEGASTAR_ZX-SH1.0-2PLT; MPN ZX-SH1.0-2PLT; LCSC Part C7430451
U7: MOTOR4; CONN-SMD_2P-P1.00_MEGASTAR_ZX-SH1.0-2PLT; MPN ZX-SH1.0-2PLT; LCSC Part C7430451
U9: MOTOR5; CONN-SMD_2P-P1.00_MEGASTAR_ZX-SH1.0-2PLT; MPN ZX-SH1.0-2PLT; LCSC Part C7430451
U10: MOTOR6; CONN-SMD_2P-P1.00_MEGASTAR_ZX-SH1.0-2PLT; MPN ZX-SH1.0-2PLT; LCSC Part C7430451
U12: MOTOR7; CONN-SMD_2P-P1.00_MEGASTAR_ZX-SH1.0-2PLT; MPN ZX-SH1.0-2PLT; LCSC Part C7430451
U13: MOTOR8; CONN-SMD_2P-P1.00_MEGASTAR_ZX-SH1.0-2PLT; MPN ZX-SH1.0-2PLT; LCSC Part C7430451
U14: POT1; CONN-SMD_3P-P1.00_HDGC_HDGC1002WV-S-3P; MPN ZX-SH1.0-3PLT; LCSC Part C7430452
U17: POT2; CONN-SMD_3P-P1.00_HDGC_HDGC1002WV-S-3P; MPN ZX-SH1.0-3PLT; LCSC Part C7430452
U18: POT3; CONN-SMD_3P-P1.00_HDGC_HDGC1002WV-S-3P; MPN ZX-SH1.0-3PLT; LCSC Part C7430452
U19: POT4; CONN-SMD_3P-P1.00_HDGC_HDGC1002WV-S-3P; MPN ZX-SH1.0-3PLT; LCSC Part C7430452
U20: POT5; CONN-SMD_3P-P1.00_HDGC_HDGC1002WV-S-3P; MPN ZX-SH1.0-3PLT; LCSC Part C7430452
U21: POT6; CONN-SMD_3P-P1.00_HDGC_HDGC1002WV-S-3P; MPN ZX-SH1.0-3PLT; LCSC Part C7430452
U22: SWD; CONN-SMD_3P-P1.00_HDGC_HDGC1002WV-S-3P; MPN ZX-SH1.0-3PLT; LCSC Part C7430452
U23: POT7; CONN-SMD_3P-P1.00_HDGC_HDGC1002WV-S-3P; MPN ZX-SH1.0-3PLT; LCSC Part C7430452
U24: POT8; CONN-SMD_3P-P1.00_HDGC_HDGC1002WV-S-3P; MPN ZX-SH1.0-3PLT; LCSC Part C7430452
Y1: 8M; Crystal_SMD_3225-4Pin_3.2x2.5mm

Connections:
+3.3V: C9.2, C31.1, C32.1, C33.1, L1.1, SW1.2, U3.1 (VBAT), U3.24 (VDD_VIO_1), U3.36 (VDD_2), U3.48 (VDD_VIO_3), U4.2 (Vout)
+3.3VA: C20.2, U14.1, U16.2 (Vout), U17.1, U18.1, U19.1, U20.1, U21.1, U23.1, U24.1
+5V: C8.2, C19.2, J1.A4 (VBUS), J1.A9 (VBUS), J1.B4 (VBUS), J1.B9 (VBUS), J8.3, U4.3 (VIN), U16.3 (VIN)
/ADC0: C21.1, R17.1, U3.10 (PA0/WKUP/ADC0)
/ADC1: C24.1, R18.1, U3.11 (PA1/ADC1)
/ADC2: C25.1, R19.1, U3.12 (PA2/ADC2)
/ADC3: C26.1, R20.1, U3.13 (PA3/ADC3)
/ADC4: C27.1, R24.1, U3.14 (PA4/ADC4/DAC0)
/ADC5: C28.1, R23.1, U3.15 (PA5/ADC5/DAC1)
/ADC6: C29.1, R22.1, U3.16 (PA6/ADC6)
/ADC7: C30.1, R21.1, U3.17 (PA7/ADC7)
/BOOT0: R1.1, SW1.1, U3.44 (BOOT0)
/OSC_IN: C3.1, U3.5 (OSC_IN/PD0), Y1.3
/OSC_OUT: C2.1, U3.6 (OSC_OUT/PD1), Y1.1
/PB6: J2.1, U3.42 (PB6)
/PB7: J2.3, U3.43 (PB7)
/SWD_CLK: U3.37 (PA14/SWCLK), U22.2
/SWD_DIO: U3.34 (PA13/SWDIO), U22.3
/TIM1_1: U3.29 (PA8), U8.10 (BIN2)
/TIM1_2: U3.30 (PA9), U8.9 (BIN1)
/TIM1_3: U3.31 (PA10), U11.16 (AIN1)
/TIM1_4: U3.32 (PA11/USB1DM), U11.15 (AIN2)
/TIM2_1: U3.38 (PA15), U11.10 (BIN2)
/TIM2_2: U3.39 (PB3), U11.9 (BIN1)
/TIM2_3: U1.10 (BIN2), U3.21 (PB10)
/TIM2_4: U1.9 (BIN1), U3.22 (PB11)
/TIM3_1: U3.40 (PB4), U15.16 (AIN1)
/TIM3_2: U3.41 (PB5), U15.15 (AIN2)
/TIM3_3: U1.16 (AIN1), U3.18 (PB0/ADC8)
/TIM3_4: U1.15 (AIN2), U3.19 (PB1/ADC9)
/TIM4_3: U3.45 (PB8), U15.10 (BIN2)
/TIM4_4: U3.46 (PB9), U15.9 (BIN1)
/USBDN: J1.A7 (D-), J1.B7 (D-), J2.2
/USBDP: J1.A6 (D+), J1.B6 (D+), J2.4
/`TIM4_1: U3.27 (PB14), U8.16 (AIN1)
/`TIM4_2: U3.28 (PB15), U8.15 (AIN2)
/~NRST: C1.1, SW2.2, U3.7 (NRST)
GND: C1.2, C2.2, C3.2, C4.2, C5.2, C6.2, C8.1, C9.1, C10.2, C11.2, C13.2, C14.2, C16.2, C17.2, C19.1, C20.1, C21.2, C22.2, C23.2, C24.2, C25.2, C26.2, C27.2, C28.2, C29.2, C30.2, C31.2, C32.2, C33.2, J1.A1 (GND), J1.A12 (GND), J1.B1 (GND), J1.B12 (GND), J7.1 (Pin_1_1), R1.2, R2.2, R3.2, R4.2, R5.2, R6.2, R9.2, R10.2, R12.2, R13.2, R15.2, R16.2, SW2.1, U1.13 (GND), U1.17 (GND), U3.8 (VSSA), U3.20 (PB2/BOOT1), U3.23 (VSS_1), U3.35 (VSS_2), U3.47 (VSS_3), U4.1 (GND), U8.13 (GND), U8.17 (GND), U11.13 (GND), U11.17 (GND), U14.3, U15.13 (GND), U15.17 (GND), U16.1 (GND), U17.3, U18.3, U19.3, U20.3, U21.3, U22.1, U23.3, U24.3, Y1.2 (G), Y1.4 (G)
unnamed: J1.A5 (CC1), R2.1
unnamed: J1.B5 (CC2), R3.1
unnamed: C4.1, J1.S1 (SHIELD), R4.1
unnamed: J6.1 (Pin_1_1), J8.1
unnamed: R17.2, U14.2
unnamed: R18.2, U17.2
unnamed: R19.2, U18.2
unnamed: R20.2, U19.2
unnamed: R21.2, U24.2
unnamed: R22.2, U23.2
unnamed: R23.2, U21.2
unnamed: R24.2, U20.2
unnamed: R5.1, U1.3 (AISEN)
unnamed: U1.2 (AOUT1), U2.2
unnamed: U1.4 (AOUT2), U2.1
unnamed: R6.1, U1.6 (BISEN)
unnamed: U1.7 (BOUT1), U5.1
unnamed: U1.5 (BOUT2), U5.2
unnamed: C7.1, U1.11 (VCP)
unnamed: C5.1, U1.14 (VINT)
unnamed: R7.1, U1.1 (~SLEEP)
unnamed: C22.1, C23.1, L1.2, U3.9 (VDDA)
unnamed: R9.1, U8.3 (AISEN)
unnamed: U6.2, U8.2 (AOUT1)
unnamed: U6.1, U8.4 (AOUT2)
unnamed: R10.1, U8.6 (BISEN)
unnamed: U7.1, U8.7 (BOUT1)
unnamed: U7.2, U8.5 (BOUT2)
unnamed: C12.1, U8.11 (VCP)
unnamed: C10.1, U8.14 (VINT)
unnamed: R8.1, U8.1 (~SLEEP)
unnamed: R12.1, U11.3 (AISEN)
unnamed: U9.2, U11.2 (AOUT1)
unnamed: U9.1, U11.4 (AOUT2)
unnamed: R13.1, U11.6 (BISEN)
unnamed: U10.1, U11.7 (BOUT1)
unnamed: U10.2, U11.5 (BOUT2)
unnamed: C15.1, U11.11 (VCP)
unnamed: C13.1, U11.14 (VINT)
unnamed: R11.1, U11.1 (~SLEEP)
unnamed: R15.1, U15.3 (AISEN)
unnamed: U12.2, U15.2 (AOUT1)
unnamed: U12.1, U15.4 (AOUT2)
unnamed: R16.1, U15.6 (BISEN)
unnamed: U13.1, U15.7 (BOUT1)
unnamed: U13.2, U15.5 (BOUT2)
unnamed: C18.1, U15.11 (VCP)
unnamed: C16.1, U15.14 (VINT)
unnamed: R14.1, U15.1 (~SLEEP)
Vdrive: C6.1, C7.2, C11.1, C12.2, C14.1, C15.2, C17.1, C18.2, J8.2, R7.2, R8.2, R11.2, R14.2, U1.12 (VM), U8.12 (VM), U11.12 (VM), U15.12 (VM)

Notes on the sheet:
`并不是定时器PWM输出，是普通GPIO

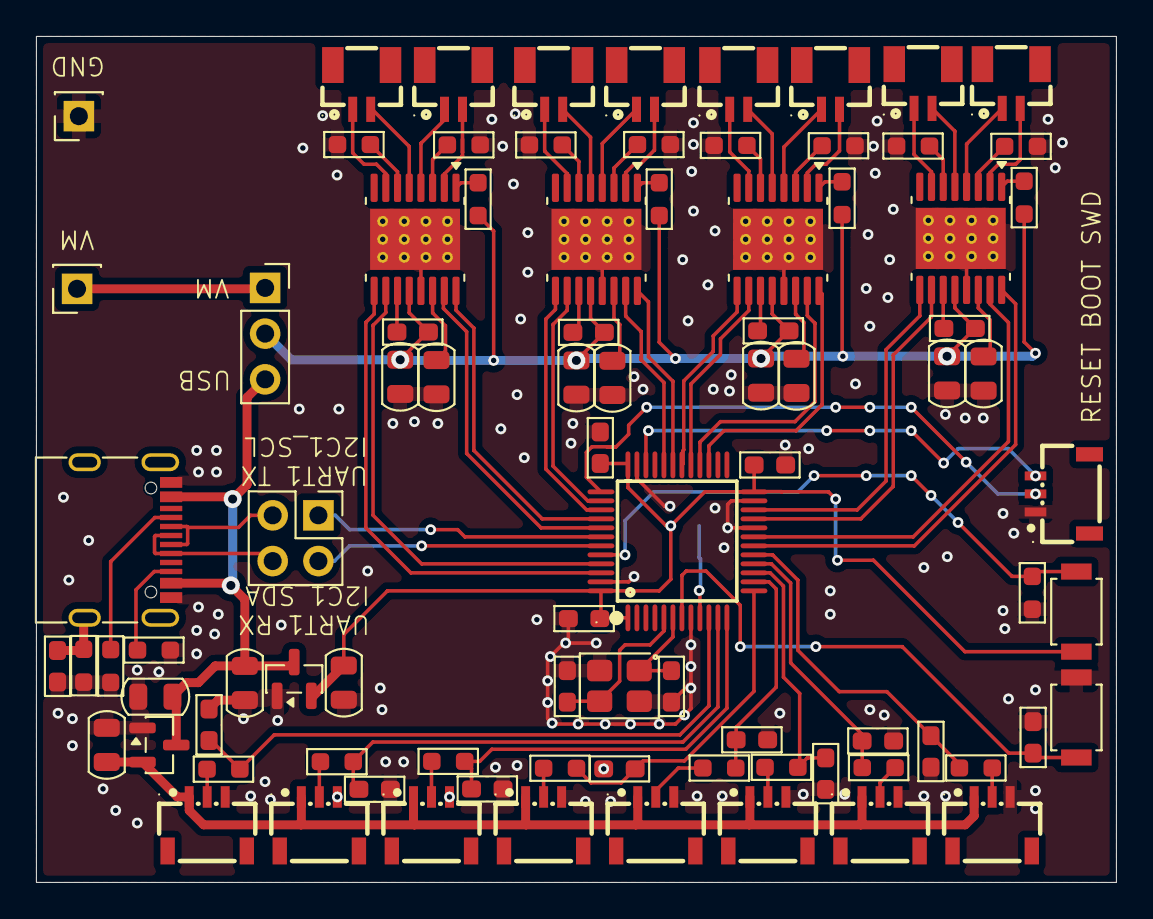
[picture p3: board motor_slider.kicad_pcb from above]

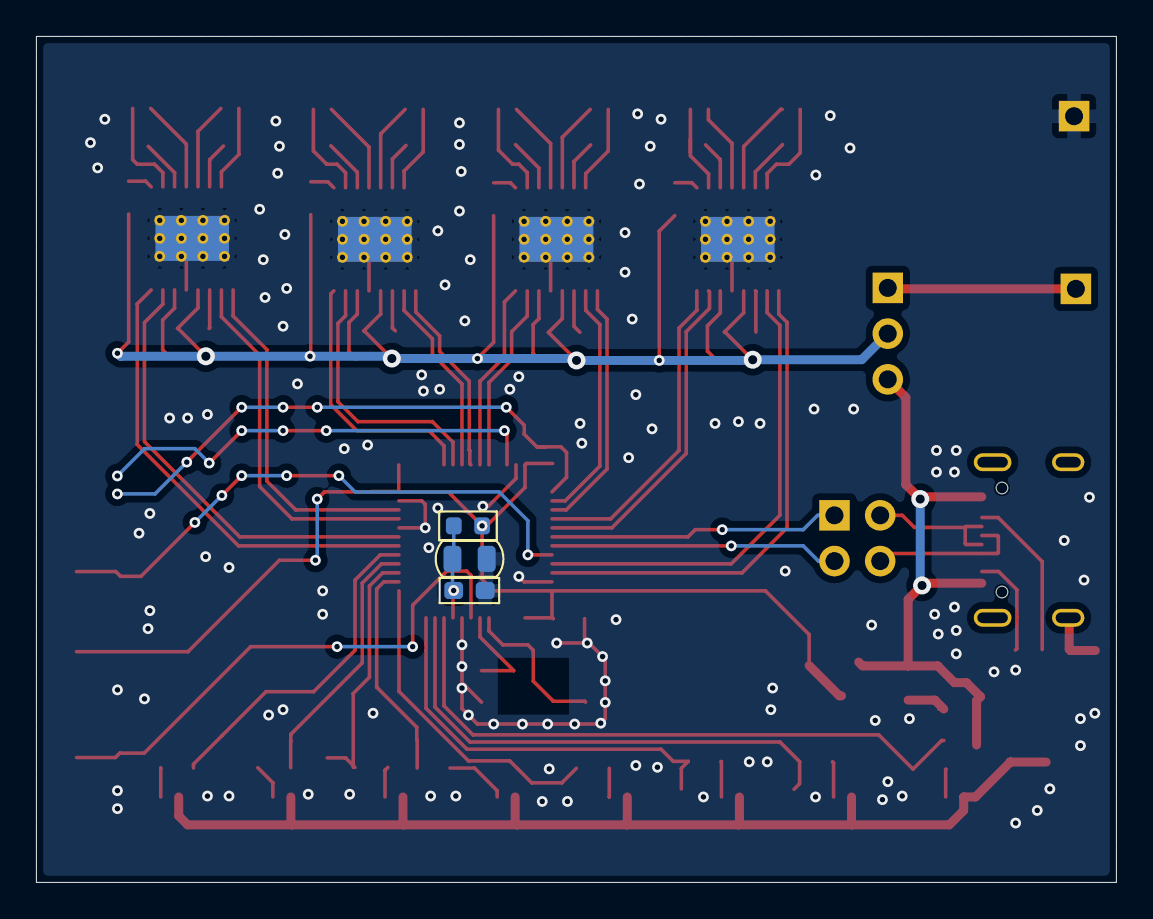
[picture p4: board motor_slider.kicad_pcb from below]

Board: 2 copper layers, 60.0 x 47.0 mm, 90 parts (3 on the bottom side), 88 nets.

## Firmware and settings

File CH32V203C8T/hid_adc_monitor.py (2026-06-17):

#!/usr/bin/env python3
"""
HID ADC Monitor — 8 路电机 ADC + 调试控制台 (PyQt6)

通过 HID1 接口接收 CH32V203C8T 固件上报的 64 字节二进制状态报告，
以列表式 GUI 显示 8 路 ADC 值、目标值、占空比和位置百分比。
同时通过 HID0 接口接收 printf 调试输出，显示在底部控制台。

依赖:
    pip install hidapi PyQt6

用法:
    python hid_adc_monitor.py
"""

import sys
import time
import struct
from dataclasses import dataclass, field
from typing import Optional, List

try:
    import hid
except ImportError:
    print("请先安装 hidapi: pip install hidapi")
    print("  pip install hidapi")
    sys.exit(1)

try:
    from PyQt6.QtCore import (
        Qt, QThread, pyqtSignal, QTimer, QMutex, QMutexLocker, QPointF
    )
    from PyQt6.QtWidgets import (
        QApplication, QMainWindow, QWidget, QVBoxLayout, QHBoxLayout,
        QLabel, QStatusBar, QPlainTextEdit, QPushButton, QSplitter,
        QSlider, QSizePolicy, QComboBox, QDoubleSpinBox, QSpinBox,
    )
    from PyQt6.QtGui import (
        QColor, QPalette, QFont, QPainter, QPen,
    )
except ImportError:
    print("请先安装 PyQt6: pip install PyQt6")
    print("  pip install PyQt6")
    sys.exit(1)


# ---------------------------------------------------------------------------
# 常量定义 (与固件 usb_impl.h 一致)
# ---------------------------------------------------------------------------
VID = 0x1A86
PID = 0x0002
HID0_USAGE_PAGE = 0xFF01   # HID0 printf 调试输出接口
HID1_USAGE_PAGE = 0xFF00   # HID1 电机控制接口
REPORT_SIZE = 64
MOTOR_COUNT = 8

# 报告格式偏移 (固件 HID1_ADC(i) / HID1_TARGET(i) / HID1_DUTY(i))
OFFSET_STATUS = 0
OFFSET_RSV     = 1
OFFSET_ACTIVE_FLAGS = 1   # uint8, 每路 1 bit active
OFFSET_ADC     = 2       # uint16 LE × 8,  偏移 2～17

# PID 定点数缩放 (与固件一致)
PID_SCALE_KP = 1000
PID_SCALE_KI = 10000
PID_SCALE_KD = 1000
OFFSET_TARGET  = 18      # uint16 LE × 8,  偏移 18～33
OFFSET_DUTY    = 34      # uint16 LE × 8,  偏移 34～49


# ---------------------------------------------------------------------------
# 数据结构
# ---------------------------------------------------------------------------
@dataclass
class MotorChannelData:
    """单路电机状态"""
    adc: int = 0
    target: int = 0
    duty: int = 0
    connected: bool = False


@dataclass
class StatusReport:
    """解析后的 HID1 状态报告"""
    running: bool = False
    active_flags: int = 0
    channels: List[MotorChannelData] = field(default_factory=list)

    @classmethod
    def from_bytes(cls, report: bytes) -> Optional["StatusReport"]:
        """从 64 字节 HID 报告解析"""
        if len(report) < REPORT_SIZE:
            return None

        result = cls()
        result.running = bool(report[OFFSET_STATUS] & 0x01)
        result.active_flags = report[OFFSET_ACTIVE_FLAGS]

        for i in range(MOTOR_COUNT):
            offs_adc = OFFSET_ADC + i * 2
            offs_target = OFFSET_TARGET + i * 2
            offs_duty = OFFSET_DUTY + i * 2

            ch = MotorChannelData(
                adc    = struct.unpack_from("<H", report, offs_adc)[0],
                target = struct.unpack_from("<H", report, offs_target)[0],
                duty   = struct.unpack_from("<H", report, offs_duty)[0],
                connected=True,
            )
            result.channels.append(ch)

        return result


# ---------------------------------------------------------------------------
# HID Worker 线程
# ---------------------------------------------------------------------------
class HidWorker(QThread):
    """后台线程: 持续读取 HID1 报告并解析"""

    data_ready = pyqtSignal(object)   # StatusReport
    connected = pyqtSignal()
    disconnected = pyqtSignal(str)     # 原因
    error_occurred = pyqtSignal(str)

    def __init__(self, parent=None):
        super().__init__(parent)
        self._running = False
        self._device: Optional[hid.device] = None
        self._mutex = QMutex()

    def send_target(self, channel: int, value: int):
        """通过 HID1 OUT 发送单路目标位置 (线程安全)"""
        report = bytearray(65)
        report[0] = 0x00   # 幻影 Report ID
        report[1] = 0x01   # 命令 ID: 设置目标
        report[2] = 1      # count = 1 (单路)
        report[3] = channel
        report[4] = value & 0xFF
        report[5] = (value >> 8) & 0xFF
        with QMutexLocker(self._mutex):
            if self._device is not None:
                try:
                    self._device.write(bytes(report))
                except Exception:
                    pass

    def send_pid(self, channel: int, kp: float, ki: float, kd: float):
        """通过 HID1 OUT 发送 PID 参数"""
        report = bytearray(65)
        report[0] = 0x00   # 幻影 Report ID
        report[1] = 0x04   # 命令 ID: 设置PID
        report[2] = channel
        def _u16(v):
            return int(v) & 0xFFFF
        kp_int = _u16(kp * PID_SCALE_KP)
        ki_int = _u16(ki * PID_SCALE_KI)
        kd_int = _u16(kd * PID_SCALE_KD)
        report[3] = kp_int & 0xFF
        report[4] = (kp_int >> 8) & 0xFF
        report[5] = ki_int & 0xFF
        report[6] = (ki_int >> 8) & 0xFF
        report[7] = kd_int & 0xFF
        report[8] = (kd_int >> 8) & 0xFF
        with QMutexLocker(self._mutex):
            if self._device is not None:
                try:
                    self._device.write(bytes(report))
                except Exception:
                    pass

    def send_pwm_bias(self, value: int):
        """通过 HID1 OUT 设置 PWM 起步偏置"""
        report = bytearray(65)
        report[0] = 0x00   # 幻影 Report ID
        report[1] = 0x05   # 命令 ID: 设置 PWM Bias
        report[2] = value & 0xFF
        report[3] = (value >> 8) & 0xFF
        with QMutexLocker(self._mutex):
            if self._device is not None:
                try:
                    self._device.write(bytes(report))
                except Exception:
                    pass

    def send_pwm_max(self, value: int):
        """通过 HID1 OUT 设置 PWM 最大占空比"""
        report = bytearray(65)
        report[0] = 0x00   # 幻影 Report ID
        report[1] = 0x06   # 命令 ID: 设置 PWM Max
        report[2] = value & 0xFF
        report[3] = (value >> 8) & 0xFF
        with QMutexLocker(self._mutex):
            if self._device is not None:
                try:
                    self._device.write(bytes(report))
                except Exception:
                    pass

    def run(self):
        self._running = True
        while self._running:
            if self._device is None:
                self._try_connect()
                if self._device is None:
                    # 未找到设备，等待后重试
                    if self._running:
                        time.sleep(0.5)
                    continue

            try:
                report = self._device.read(REPORT_SIZE, timeout_ms=200)
                if report:
                    parsed = StatusReport.from_bytes(bytes(report))
                    if parsed:
                        self.data_ready.emit(parsed)
            except (OSError, IOError) as e:
                self._on_disconnect(f"设备断开: {e}")
            except Exception as e:
                self.error_occurred.emit(f"HID 读取错误: {e}")
                time.sleep(0.5)

        self._close_device()

    def stop(self):
        """安全停止线程"""
        self._running = False
        # 不等待 — 线程循环中的 sleep/read 会因 timeout 自然退出

    def _try_connect(self):
        """枚举并打开 HID1 设备"""
        try:
            devices = hid.enumerate(VID, PID)
        except Exception as e:
            self.error_occurred.emit(f"枚举设备失败: {e}")
            return

        target_path = None
        for d in devices:
            if d.get("usage_page") == HID1_USAGE_PAGE:
                target_path = d["path"]
                break

        if target_path is None:
            return  # 无匹配设备

        try:
            dev = hid.device()
            dev.open_path(target_path)
            self._device = dev
            self.connected.emit()
        except Exception as e:
            self.error_occurred.emit(f"HID1 打开失败: {e}")
            self._device = None

    def _close_device(self):
        if self._device is not None:
            try:
                self._device.close()
            except Exception:
                pass
            self._device = None

    def _on_disconnect(self, reason: str):
        self._close_device()
        self.disconnected.emit(reason)


# ---------------------------------------------------------------------------
# HID Debug Worker (HID0 printf)
# ---------------------------------------------------------------------------
class HidDebugWorker(QThread):
    """后台线程: 持续读取 HID0 printf 输出, 按行发射"""

    text_ready = pyqtSignal(str)       # 完整一行文本
    connected = pyqtSignal()
    disconnected = pyqtSignal(str)
    error_occurred = pyqtSignal(str)

    def __init__(self, parent=None):
        super().__init__(parent)
        self._running = False
        self._device: Optional[hid.device] = None
        self._line_buf = bytearray()    # 缓存不完整的行

    def run(self):
        self._running = True
        while self._running:
            if self._device is None:
                self._try_connect()
                if self._device is None:
                    if self._running:
                        time.sleep(0.5)
                    continue

            try:
                report = self._device.read(REPORT_SIZE, timeout_ms=200)
                if report:
                    self._feed(bytes(report))
            except (OSError, IOError) as e:
                self._on_disconnect(f"设备断开: {e}")
            except Exception as e:
                self.error_occurred.emit(f"HID0 读取错误: {e}")
                time.sleep(0.5)

        self._close_device()

    def stop(self):
        self._running = False

    def _try_connect(self):
        try:
            devices = hid.enumerate(VID, PID)
        except Exception as e:
            self.error_occurred.emit(f"枚举设备失败: {e}")
            return

        target_path = None
        for d in devices:
            if d.get("usage_page") == HID0_USAGE_PAGE:
                target_path = d["path"]
                break

        if target_path is None:
            return

        try:
            dev = hid.device()
            dev.open_path(target_path)
            self._device = dev
            self.connected.emit()
        except Exception as e:
            self.error_occurred.emit(f"HID0 打开失败: {e}")
            self._device = None

    def _close_device(self):
        if self._device is not None:
            try:
                self._device.close()
            except Exception:
                pass
            self._device = None

    def _on_disconnect(self, reason: str):
        self._close_device()
        self.disconnected.emit(reason)

    def _feed(self, report: bytes):
        """处理一帧 HID0 报告: [count(1B) | text(count B) | padding]"""
        if len(report) < 1:
            return
        count = report[0]
        if count == 0 or count > len(report) - 1:
            return
        payload = report[1:1 + count]
        self._line_buf.extend(payload)

        # 分割出完整行 (\r\n 或 \n)
        while True:
            idx = self._line_buf.find(b'\n')
            if idx < 0:
                break
            line = self._line_buf[:idx]
            self._line_buf = self._line_buf[idx + 1:]

            # 去除尾部 \r (CRLF 情况)
            if line.endswith(b'\r'):
                line = line[:-1]

            if line:
                try:
                    text = line.decode('utf-8', errors='replace')
                except Exception:
                    text = repr(line)
                self.text_ready.emit(text)


# ---------------------------------------------------------------------------
# ADC 指示器 (自定义绘制: 竖线 + 横线标记)
# ---------------------------------------------------------------------------
class AdcIndicator(QWidget):
    """垂直竖线 + 横线标记，表示当前 ADC 值位置"""

    def __init__(self, parent=None):
        super().__init__(parent)
        self._value = 0
        self.setMinimumWidth(16)

    def set_value(self, value: int):
        self._value = max(0, min(4095, value))
        self.update()

    def paintEvent(self, event):
        painter = QPainter(self)
        w = self.width()
        h = self.height()

        # 竖线 (中心)
        pen = QPen(QColor("#999"))
        pen.setWidth(2)
        painter.setPen(pen)
        cx = w // 2
        margin = 4
        painter.drawLine(cx, margin, cx, h - margin)

        # 横线标记 (ADC 位置)
        pos_ratio = self._value / 4095.0
        y = h - margin - int(pos_ratio * (h - 2 * margin))
        y = max(margin, min(h - margin, y))

        marker_pen = QPen(QColor("#4CAF50"))
        marker_pen.setWidth(3)
        painter.setPen(marker_pen)
        painter.drawLine(cx - 7, y, cx + 7, y)

        painter.end()


# ---------------------------------------------------------------------------
# 电位器部件 (Slider + ADC 指示器 + PWM 数字)
# ---------------------------------------------------------------------------
class PotWidget(QWidget):
    """单个电位器控件: 可拖动 Slider (目标) + 竖线指示器 (ADC) + PWM 数字"""

    target_changed = pyqtSignal(int, int)  # (channel, value)

    def __init__(self, channel: int, parent=None):
        super().__init__(parent)
        self._channel = channel  # 0-based
        self._adc = 0
        self._target = 2048
        self._duty = 0

        layout = QVBoxLayout(self)
        layout.setContentsMargins(3, 2, 3, 2)
        layout.setSpacing(1)

        # CH 标签
        self._ch_label = QLabel(f"CH{channel + 1}")
        self._ch_label.setAlignment(Qt.AlignmentFlag.AlignCenter)
        font = QFont("Consolas", 9)
        self._ch_label.setFont(font)
        layout.addWidget(self._ch_label)

        # Slider + ADC 指示器
        indicator_area = QWidget()
        indicator_layout = QHBoxLayout(indicator_area)
        indicator_layout.setContentsMargins(0, 0, 0, 0)
        indicator_layout.setSpacing(0)

        self._slider = QSlider(Qt.Orientation.Vertical)
        self._slider.setRange(0, 4095)
        self._slider.setValue(2048)
        self._slider.setTickPosition(QSlider.TickPosition.NoTicks)
        self._slider.valueChanged.connect(self._on_slider_changed)
        indicator_layout.addWidget(self._slider)

        self._adc_indicator = AdcIndicator()
        indicator_layout.addWidget(self._adc_indicator)

        layout.addWidget(indicator_area, stretch=1)

        # 数值标签: ADC + PWM
        self._value_label = QLabel("ADC:0  PWM:0")
        self._value_label.setAlignment(Qt.AlignmentFlag.AlignCenter)
        self._value_label.setFont(QFont("Consolas", 8))
        layout.addWidget(self._value_label)

    def update_data(self, adc: int, target: int, duty: int):
        self._adc = adc
        self._target = target
        self._duty = duty

        # 更新 ADC 指示器 (当前值)
        self._adc_indicator.set_value(adc)

        # 更新数字
        self._value_label.setText(f"ADC:{adc}  PWM:{duty}")

    def _on_slider_changed(self, value: int):
        """Slider 拖动 -> 更新本地目标 + 通知主窗口发送 HID1"""
        self._target = value
        self.target_changed.emit(self._channel, value)
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

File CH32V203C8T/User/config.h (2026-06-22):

/**
 * @file    config.h
 * @brief   可配置参数 — 闭环控制、PID、电机行为
 *
 * @note    修改后需重新编译固件
 */
#pragma once

// ------------------------------------------------------------
// 电机控制器
// ------------------------------------------------------------

/** @brief ADC 误差阈值，|adc - target| ≤ CTRL_ERROR_THRESHOLD 视为到达 */
#define CTRL_ERROR_THRESHOLD 2

/** @brief 到位稳定时间 (ms)，连续满足到位条件达到该时间才停止 */
#define CTRL_SETTLE_MS 5

/** @brief 静止判定阈值，相邻控制周期 ADC 变化量 ≤ 该值视为静止 */
#define CTRL_STILL_THRESHOLD 4

/** @brief 闭环超时 (ms)，超过此时间未到达目标则停止电机 */
#define CTRL_TIMEOUT_MS 1000

/** @brief 电机控制周期 (us)，250us = 4kHz */
#define CTRL_LOOP_US 250

/** @brief 控制用 ADC 一阶 IIR 滤波强度，1=快，2=较稳，3=更稳但延迟更大 */
#define CTRL_ADC_FILTER_SHIFT 2

/** @brief 目标变化小于等于该阈值时直接吸附，不启动电机 */
#define CTRL_TARGET_SNAP_THRESHOLD 3

/** @brief PID 输出绝对值小于该阈值时视为 0，不叠加 PWM_BIAS */
#define CTRL_OUTPUT_DEADBAND 2.0f

/** @brief 目标附近小于等于该阈值时禁止反向驱动，避免来回敲击 */
#define CTRL_REVERSE_THRESHOLD 6

// ------------------------------------------------------------
// pid控制器
// ------------------------------------------------------------

/** @brief 默认 PID 增益 (Motor_InitControl 中使用的初始值) */
#define PID_DEFAULT_KP 0.05f
#define PID_DEFAULT_KI 0.0001f

/** @brief PID 积分限幅，防止积分饱和 */
#define PID_INTEGRAL_LIMIT 1.0e4f

/** @brief PWM 最小起步占空比，克服静摩擦 */
#define PWM_BIAS 780

/** @brief PWM 最大占空比 (0~999) */
#define PWM_MAX 999

// ------------------------------------------------------------
// hid debug
// ------------------------------------------------------------

/** @brief HID0 printf FIFO 缓冲区大小 (字节)，必须为 2 的幂 */
#define HID_FIFO_SIZE 512

// ------------------------------------------------------------
// midi
// ------------------------------------------------------------

/** @brief MIDI 专用 ADC 平均采样次数 */
#define MIDI_ADC_AVG_COUNT 8

/** @brief MIDI CC 候选值连续出现该次数后才发送 */
#define MIDI_CC_CONFIRM_COUNT 2

/** @brief MIDI ADC 转 CC 的边界死区，单位 ADC */
#define MIDI_CC_BOUNDARY_GAP_ADC 12

/** @brief 发送后接收抑制时间 (ms)，防止 MIDI 回环反馈 */
#define CONFIG_MIDI_SEND_GAP_TIME 10

/** @brief 接收后发送抑制时间 (ms)，等待电机稳定 */
#define CONFIG_MIDI_RECEIVE_GAP_TIME 50

#define MIDI_TX_FIFO_SIZE 128

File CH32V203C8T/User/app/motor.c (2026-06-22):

#include "motor.h"

#include "bsp/tick.h"
#include "config.h"
#include "pid.h"
#include "usb/usb_impl.h"

#include <stdio.h>

// ------------------------------------------------------------
// variable
// ------------------------------------------------------------

/* 电机状态数组 */
static struct MotorState motor_states_[kMotorIdx_Count];
static uint16_t pwm_bias_ = PWM_BIAS;
static uint16_t pwm_max_ = PWM_MAX;

static void _Motor_ReinitPidLimits(void) {
    for (uint8_t i = 0; i < kMotorIdx_Count; i++) {
        Pid_Init(&motor_states_[i].pid_, motor_states_[i].pid_.kp, motor_states_[i].pid_.ki, pwm_bias_, pwm_max_);
    }
}

static uint16_t _Motor_FilterAdc(struct MotorState* state, uint16_t raw_adc) {
    uint32_t raw_q8 = (uint32_t)raw_adc << 8;
    uint32_t filtered_q8 = state->filtered_adc_q8_;

    if (raw_q8 >= filtered_q8) {
        uint32_t step = (raw_q8 - filtered_q8) >> CTRL_ADC_FILTER_SHIFT;
        if (step == 0 && raw_q8 != filtered_q8) {
            step = 1;
        }
        filtered_q8 += step;
    }
    else {
        uint32_t step = (filtered_q8 - raw_q8) >> CTRL_ADC_FILTER_SHIFT;
        if (step == 0) {
            step = 1;
        }
        filtered_q8 -= step;
    }

    state->filtered_adc_q8_ = filtered_q8;
    return (uint16_t)((filtered_q8 + 128) >> 8);
}

static int16_t _Motor_AbsI16(int16_t value) {
    return (value < 0) ? -value : value;
}

// ------------------------------------------------------------
// publci
// ------------------------------------------------------------

void Motor_InitControl(void) {
    for (int i = 0; i < kMotorIdx_Count; i++) {
        motor_states_[i].target_adc_ = 2048;
        motor_states_[i].current_adc_ = 2048;
        motor_states_[i].filtered_adc_q8_ = (uint32_t)2048 << 8;
        motor_states_[i].dir_ = kMotorDir_Stop;
        motor_states_[i].duty_ = 0;
        motor_states_[i].active_ = false;
        motor_states_[i].start_tick_ = 0;
        motor_states_[i].last_adc_ = 2048;
        motor_states_[i].settle_tick_ = 0;
        motor_states_[i].settling_ = false;
        Pid_Init(&motor_states_[i].pid_, PID_DEFAULT_KP, PID_DEFAULT_KI, pwm_bias_, pwm_max_);
    }
}

void Motor_StartAdcConversion(void) {
    MotorHw_StartAdcConversion();
}

bool Motor_IsAdcReady(void) {
    return MotorHw_IsAdcReady();
}

void Motor_RunControlLoop(void) {
    uint16_t raw_adc[kMotorIdx_Count];
    uint32_t now_tick = Tick_Get();

    MotorHw_GetAdcValue(raw_adc);
    Motor_OnRawAdcReady(raw_adc);
    {
        uint16_t filter_adc[kMotorIdx_Count];
        for (int i = 0; i < kMotorIdx_Count; ++i) {
            motor_states_[i].current_adc_ = _Motor_FilterAdc(&motor_states_[i], raw_adc[i]);
            filter_adc[i] = motor_states_[i].current_adc_;
        }
        Motor_OnFilterAdcReady(filter_adc);
    }

    for (int i = 0; i < kMotorIdx_Count; i++) {
        // 非活跃电机：跳过，PWM 保持 0
        if (!motor_states_[i].active_)
            continue;

        // 判断是否到达目标
        int16_t diff = (int16_t)(motor_states_[i].target_adc_ - motor_states_[i].current_adc_);
        int16_t abs_diff = _Motor_AbsI16(diff);
        int16_t adc_delta = (int16_t)(motor_states_[i].current_adc_ - motor_states_[i].last_adc_);
        int16_t abs_adc_delta = _Motor_AbsI16(adc_delta);

        if (abs_diff <= CTRL_ERROR_THRESHOLD && abs_adc_delta <= CTRL_STILL_THRESHOLD) {
            if (!motor_states_[i].settling_) {
                motor_states_[i].settle_tick_ = now_tick;
                motor_states_[i].settling_ = true;
            }
        }
        else {
            motor_states_[i].settling_ = false;
        }
        motor_states_[i].last_adc_ = motor_states_[i].current_adc_;

        if (motor_states_[i].settling_ && (uint32_t)(now_tick - motor_states_[i].settle_tick_) >= CTRL_SETTLE_MS) {
            motor_states_[i].active_ = false;
            Motor_OnActiveChanged(i, false);
            motor_states_[i].duty_ = 0;
            MotorHw_SetPwm(i, kMotorDir_Stop, 0);
            continue;
        }

        // 超时判断
        if ((uint32_t)(now_tick - motor_states_[i].start_tick_) >= CTRL_TIMEOUT_MS) {
            motor_states_[i].active_ = false;
            Motor_OnActiveChanged(i, false);
            motor_states_[i].duty_ = 0;
            MotorHw_SetPwm(i, kMotorDir_Stop, 0);
            continue;
        }

        float output = Pid_Update(&motor_states_[i].pid_, (float)motor_states_[i].target_adc_,
                                  (float)motor_states_[i].current_adc_);

        enum MotorDir next_dir = kMotorDir_Stop;
        if (output >= CTRL_OUTPUT_DEADBAND) {
            next_dir = kMotorDir_Forward;
        }
        else if (output <= -CTRL_OUTPUT_DEADBAND) {
            next_dir = kMotorDir_Reverse;
        }

        if (next_dir != kMotorDir_Stop && motor_states_[i].dir_ != kMotorDir_Stop && next_dir != motor_states_[i].dir_
            && abs_diff <= CTRL_REVERSE_THRESHOLD) {
            next_dir = kMotorDir_Stop;
            Pid_Reset(&motor_states_[i].pid_);
        }

        if (next_dir == kMotorDir_Forward) {
            motor_states_[i].dir_ = kMotorDir_Forward;
            motor_states_[i].duty_ = (uint16_t)output + pwm_bias_;
        }
        else if (next_dir == kMotorDir_Reverse) {
            motor_states_[i].dir_ = kMotorDir_Reverse;
            motor_states_[i].duty_ = (uint16_t)(-output) + pwm_bias_;
        }
        else {
            motor_states_[i].dir_ = kMotorDir_Stop;
            motor_states_[i].duty_ = 0;
        }

        MotorHw_SetPwm(i, motor_states_[i].dir_, motor_states_[i].duty_);
    }
}

void Motor_SetTarget(uint8_t ch, uint16_t target_adc) {
    int16_t diff = (int16_t)(target_adc - motor_states_[ch].current_adc_);

    motor_states_[ch].target_adc_ = target_adc;
    if (_Motor_AbsI16(diff) <= CTRL_TARGET_SNAP_THRESHOLD) {
        motor_states_[ch].active_ = false;
        motor_states_[ch].dir_ = kMotorDir_Stop;
        motor_states_[ch].duty_ = 0;
        motor_states_[ch].settling_ = false;
        Pid_Reset(&motor_states_[ch].pid_);
        MotorHw_SetPwm(ch, kMotorDir_Stop, 0);
        Motor_OnActiveChanged(ch, false);
        return;
    }

    motor_states_[ch].active_ = true;
    motor_states_[ch].start_tick_ = Tick_Get();
    motor_states_[ch].last_adc_ = motor_states_[ch].current_adc_;
    motor_states_[ch].settle_tick_ = 0;
    motor_states_[ch].settling_ = false;
    Pid_Reset(&motor_states_[ch].pid_);
    Motor_OnActiveChanged(ch, true);
}

void Motor_StopAll(void) {
    for (int i = 0; i < kMotorIdx_Count; i++) {
        motor_states_[i].active_ = false;
        motor_states_[i].start_tick_ = 0;
        motor_states_[i].settle_tick_ = 0;
        motor_states_[i].settling_ = false;
        MotorHw_SetPwm(i, kMotorDir_Stop, 0);
        Motor_OnActiveChanged(i, false);
    }
}
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

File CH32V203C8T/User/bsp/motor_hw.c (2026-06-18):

#include "motor_hw.h"

#include "ch32v20x_adc.h"
#include "ch32v20x_dma.h"
#include "ch32v20x_gpio.h"
#include "ch32v20x_rcc.h"
#include "ch32v20x_tim.h"

// ------------------------------------------------------------
// variable
// ------------------------------------------------------------

#define MOTOR5_PDM_STEPS 1000

#define MOTOR5_IN1_SET   ((uint32_t)GPIO_Pin_14)
#define MOTOR5_IN2_SET   ((uint32_t)GPIO_Pin_15)
#define MOTOR5_IN1_RESET ((uint32_t)GPIO_Pin_14 << 16)
#define MOTOR5_IN2_RESET ((uint32_t)GPIO_Pin_15 << 16)
#define MOTOR5_BOTH_LOW  (MOTOR5_IN1_RESET | MOTOR5_IN2_RESET)
// 电机 5 使用 TIM1_UP 以 96kHz 触发 DMA 刷 GPIOB->BSHR。
// 1000 点循环表对应 96Hz 的完整重复周期，表内用误差累加把脉冲均匀打散。
#define MOTOR5_PDM_DUTY_DEADBAND 2

__attribute__((aligned(4)))
static volatile uint16_t motor_adc_dma_buf_[kMotorIdx_Count];
static volatile bool motor_adc_ready_;

__attribute__((aligned(4)))
static uint32_t motor5_pdm_dma_buf_[MOTOR5_PDM_STEPS];
static enum MotorDir motor5_pdm_dir_ = kMotorDir_Stop;
static uint16_t motor5_pdm_duty_ = 0xFFFF;
// true 表示 DMA1_Channel5 正在响应 TIM1 update request。
// 运行中 duty 变化只重填 buffer，不重启 DMA，避免相位反复归零。
static bool motor5_pdm_running_;

// ------------------------------------------------------------
// private
// ------------------------------------------------------------

/**
 * @brief   根据电机方向生成 GPIOB->BSHR 写入值
 * @param   dir 电机方向
 * @return  BSHR 32 位值 (SET 低半字, RESET 高半字)
 */
static uint32_t _Motor5BuildPdmOnValue(enum MotorDir dir) {
    switch (dir) {
        case kMotorDir_Forward:
            return MOTOR5_IN2_SET | MOTOR5_IN1_RESET;

        case kMotorDir_Reverse:
            return MOTOR5_IN1_SET | MOTOR5_IN2_RESET;

        case kMotorDir_Brake:
            return MOTOR5_IN1_SET | MOTOR5_IN2_SET;

        case kMotorDir_Stop:
        default:
            return MOTOR5_BOTH_LOW;
    }
}

/**
 * @brief   用 Bresenham/PDM 算法填充 DMA 缓冲区
 *          将 duty/MOTOR5_PDM_STEPS 占空比均匀分散到 1000 点循环表中，
 *          避免前 N 点全高造成 96Hz 低频 PWM 分量。
 * @param   dir  电机方向 (Stop/0 duty 时直接返回)
 * @param   duty 占空比 0~999
 */
static void _Motor5FillPdmBuffer(enum MotorDir dir, uint16_t duty) {
    uint32_t acc = 0;
    uint32_t on_value = _Motor5BuildPdmOnValue(dir);

    if (dir == kMotorDir_Stop || duty == 0) {
        return;
    }

    for (uint16_t i = 0; i < MOTOR5_PDM_STEPS; ++i) {
        // Bresenham/PDM 风格分散脉冲，避免前 N 点全高造成 96Hz 低频 PWM。
        acc += duty;
        if (acc >= MOTOR5_PDM_STEPS) {
            acc -= MOTOR5_PDM_STEPS;
            motor5_pdm_dma_buf_[i] = on_value;
        }
        else {
            motor5_pdm_dma_buf_[i] = MOTOR5_BOTH_LOW;
        }
    }
}

/**
 * @brief   启动电机 5 PDM DMA 传输
 *          利用 TIM1 update 事件触发 DMA1_Channel5 向 GPIOB->BSHR 刷数据，
 *          不干扰 TIM1 已有的硬件 PWM 输出。
 */
static void _Motor5StartPdm(void) {
    if (motor5_pdm_running_) {
        return;
    }

    // TIM1 本身继续负责已有硬件 PWM；这里只启用 update DMA request。
    DMA_Cmd(DMA1_Channel5, DISABLE);
    DMA1_Channel5->MADDR = (uint32_t)motor5_pdm_dma_buf_;
    DMA_ClearFlag(DMA1_FLAG_GL5);
    DMA1_Channel5->CNTR = MOTOR5_PDM_STEPS;
    DMA_Cmd(DMA1_Channel5, ENABLE);
    TIM_DMACmd(TIM1, TIM_DMA_Update, ENABLE);
    motor5_pdm_running_ = true;
}

/**
 * @brief   停止电机 5 PDM DMA 传输
 *          直接关 DMA 和 update request，比持续刷全低表更省总线。
 */
static void _Motor5StopPdm(void) {
    if (!motor5_pdm_running_) {
        GPIO_ResetBits(GPIOB, GPIO_Pin_14 | GPIO_Pin_15);
        return;
    }

    // 停机时直接关 DMA 和 update request，比持续刷全低表更省总线。
    TIM_DMACmd(TIM1, TIM_DMA_Update, DISABLE);
    DMA_Cmd(DMA1_Channel5, DISABLE);
    GPIO_ResetBits(GPIOB, GPIO_Pin_14 | GPIO_Pin_15);
    motor5_pdm_running_ = false;
}

/**
 * @brief   判断是否需要更新 PDM 缓冲区
 *          方向变化或 duty 变化超过死区阈值时返回 true，
 *          避免 PID 小幅抖动触发频繁重填 1000 点表。
 * @param   dir  新方向
 * @param   duty 新占空比
 * @return  true 需要更新
 */
static bool _Motor5PdmShouldUpdate(enum MotorDir dir, uint16_t duty) {
    if (motor5_pdm_dir_ != dir) {
        return true;
    }

    // PID 输出的小幅抖动没有必要重填 1000 点表。
    uint16_t diff = (duty > motor5_pdm_duty_) ? (duty - motor5_pdm_duty_) : (motor5_pdm_duty_ - duty);
    return diff > MOTOR5_PDM_DUTY_DEADBAND;
}

/**
 * @brief   设置电机 5 PDM 输出
 *          Stop/0 duty 时停止 DMA；否则按需重填缓冲区后启动 DMA。
 *          运行中 duty 变化只重填 buffer，不重启 DMA，避免相位反复归零。
 * @param   dir  电机方向
 * @param   duty 占空比 0~999
 */
static void _Motor5SetPdm(enum MotorDir dir, uint16_t duty) {
    if (dir == kMotorDir_Stop || duty == 0) {
        motor5_pdm_dir_ = dir;
        motor5_pdm_duty_ = duty;
        _Motor5StopPdm();
        return;
    }

    if (_Motor5PdmShouldUpdate(dir, duty)) {
        _Motor5FillPdmBuffer(dir, duty);
        motor5_pdm_dir_ = dir;
        motor5_pdm_duty_ = duty;
    }

    _Motor5StartPdm();
}

/**
 * @brief   初始化电机 5 PDM DMA 通道 (DMA1_Channel5)
 *          配置为 TIM1 update 触发、内存→GPIOB->BSHR、循环模式。
 */
static void _InitMotor5PdmDma(void) {
    DMA_InitTypeDef dma;

    _Motor5FillPdmBuffer(kMotorDir_Stop, 0);
    motor5_pdm_dir_ = kMotorDir_Stop;
    motor5_pdm_duty_ = 0;
    motor5_pdm_running_ = false;

    RCC_AHBPeriphClockCmd(RCC_AHBPeriph_DMA1, ENABLE);

    DMA_DeInit(DMA1_Channel5);
    dma.DMA_PeripheralBaseAddr = (uint32_t)&GPIOB->BSHR;
    dma.DMA_MemoryBaseAddr = (uint32_t)motor5_pdm_dma_buf_;
    dma.DMA_DIR = DMA_DIR_PeripheralDST;
    dma.DMA_BufferSize = MOTOR5_PDM_STEPS;
    dma.DMA_PeripheralInc = DMA_PeripheralInc_Disable;
    dma.DMA_MemoryInc = DMA_MemoryInc_Enable;
    dma.DMA_PeripheralDataSize = DMA_PeripheralDataSize_Word;
    dma.DMA_MemoryDataSize = DMA_MemoryDataSize_Word;
    dma.DMA_Mode = DMA_Mode_Circular;
    dma.DMA_Priority = DMA_Priority_Medium;
    dma.DMA_M2M = DMA_M2M_Disable;
    DMA_Init(DMA1_Channel5, &dma);

    DMA_ClearFlag(DMA1_FLAG_GL5);
    _Motor5StopPdm();
}
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

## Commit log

2026-06-11 usb hid printf
2026-06-12 kfifo改为柔性数组实现
2026-06-12 feat：实现 HID1 接口用于电机控制，并与现有 USB 功能集成
    - 添加了用于电机控制的 HID1 报告缓冲区和命令处理。
    - 更新了 USB 端点初始化，以包含用于 IN/OUT 通信的 HID1。
    - 创建了电机控制架构，集成了 PWM 和 ADC。
    - 实现了闭环电机位置控制的 PID 控制逻辑。
    - 提升了电机控制系统和 USB 通信的文档。
    - 添加了用于电机和 PID 控制逻辑的新文件，包括 ADC 和 DMA 设置。
2026-06-12 规范化代码
2026-06-12 hid和上位机工作
2026-06-12 重构上位机界面
2026-06-12 让上位机真的可以控制
2026-06-12 添加上位机PID控制，clang-format文件
2026-06-13 refactor: 更新电机设置协议
2026-06-13 fix: 2/3/4通道方向反向
2026-06-14 fix: 修复上位机控制电机时实际控制的是反向序号的电机
2026-06-14 refactor: 更新硬件pcb
    [motor_slider.kicad_pcb]
2026-06-15 refactor: 重新整理所有文件
2026-06-15 fix: pwm在adc前初始化避免意外的adc不工作
2026-06-15 refactor: 将pid的输出从[0,1000)修改为800+[0,200)
2026-06-17 feat: add PWM control functionality to HID ADC monitor
    - Introduced new methods in HidWorker for sending PWM bias and max values via HID1 OUT.
    - Added UI elements in MainWindow for PWM Bias and Max settings, including spin boxes and send buttons.
    - Implemented signal-slot connections for the new PWM controls to handle user input and send commands.
2026-06-17 feat: 添加 MIDI 控制的 ADC 滤波和确认机制
2026-06-17 refactor: HID printf无需中断干预
2026-06-17 refactor: systick计时器
2026-06-17 chore: 电机控制注释
2026-06-17 refactor: midi cc 转换器
2026-06-17 chore: 删除kicad备份文件夹，修改文档
2026-06-17 chore: 更新readme
2026-06-17 chore: 重新整理代码块
2026-06-18 feat: 使用TIM+DMA写GPIO的形式给电机5提供PWM
2026-06-22 refactor: midi tx/rx 使用时间gap阻止误触发 midi直接使用电机控制器的数据滤波器
